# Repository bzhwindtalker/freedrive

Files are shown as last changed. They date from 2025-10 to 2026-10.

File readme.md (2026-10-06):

# Freedrive — Open Foil Assist

A lightweight, open-source electric **foil assist** system for riders who want help getting on foil without turning their setup into a full e-foil.

> Built in the open, tested in real water, and continuously improved with community feedback.

Freedrive full setup

---

## News

### 2026-10-06 — Season 4 turbine: first water test passed
- **Jet drive (turbine) first water test passed** (13 Sept): the S4 ducted-jet unit starts the small board and flies the big board with pumping. Max draw 41V/65A ≈ 2.66 kW. Motor-off touchdown drags, motor-on is clean.
- **5085 motor + titanium blades validated**: ~400 g lighter than the 6384 setup, smoothest feel of all tested motors.
- Test videos: [13 septembre 2026](https://www.youtube.com/watch?v=aBwcKk_be1A), [End of battery](https://www.youtube.com/watch?v=OXS7Xq_WdP4).
- Full log, photos and test data: [docs/turbine-development.md](docs/turbine-development.md)

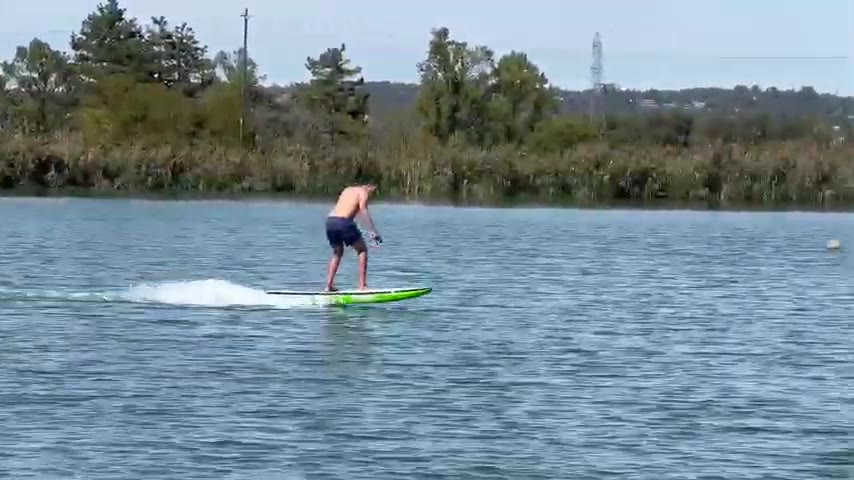
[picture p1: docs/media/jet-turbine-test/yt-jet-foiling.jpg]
S4 jet first test — foiling


### 2026-06 — 5085 motor testing + titanium blades
- 5085 motor ordered (same as @foilstate's proven design), ~400 g savings over the 6384 setup. Pod hacked, first water test 16 May.
- Titanium blades received 6 June and tested 15 June: zero post-processing, much sharper edges than alu.
- Community builds: **tkfoil** (Germany) replica reached 2.3 kW+ and 30+ starts/session. **Mikey** housing for Flysky 74100.
- Details below in "Latest verified updates".

### 2026-02 — Reliability updates
- EVA foam gaskets field-proven. Move to titanium screws after M8 stainless failures.
- No-CNC build path confirmed: print at home or via services (Craftcloud / Prototi).
- Corsica community build assembled with RS50 tabless cells (5.15 Ah).

Older entries: [NEWS.md](NEWS.md)

---

## Why Freedrive

- **Assist, not full propulsion**: designed for starts and recovery, not long-distance motoring.
- **Low-drag architecture**: slim under-board pod concept.
- **Open hardware workflow**: CAD, print files, wiring, and VESC configs are in this repo.
- **Field-proven iterations**: developed through long-term testing and community builds.

---

## Community Builds

Freedrive files have been shared with 15+ builders since Season 2. Active community replication builds in 2026 include:

| Builder | Location | Status | Notes |
| :--- | :--- | :--- | :--- |
| **tkfoil** | Germany | ✅ Running | Full replica, 2.3kW+, 30+ starts/session, FD LR6 prop |
| **Mikey** | — | 🔄 In progress | Housing adapted for Flysky 74100 VESC |
| Corsica builder | France | ✅ Running | RS50 tabless cells, custom blades |

See the [foil.zone development thread](https://foil.zone/t/light-assist-season-3/24787) for detailed build logs and ongoing discussions.

---

## Latest verified updates (June 2026)

From the build thread on foil.zone:

### 5085 Motor Testing — Weight Reduction Path
- **Post #208** — **5085 motor** ordered (same as @foilstate's proven design), targeting **~400g weight savings** over the 6384 reference setup.
- **Post #211–#220** — 5085 pod hacked and first water test completed with carbon prop + cotter pins. Despite unbalanced prop and improvised blade mounting, the motor performed well for flat-water starts. Confirmed sufficient for wave/DW assist with small board at 66kg/1600cm² foil.
- **Post #256** — **Titanium blades** received and ready for testing — expected to eliminate blade failure risk.

### Community Replication Builds
- **tkfoil** (Posts #188–#259) — Full replica build from scratch: Craft Cloud aluminum prints, custom spot-welded 12S1P battery with casting epoxy, external antenna setup. After VESC tuning (phase current 125A+, ERPM limit 35k), achieved **2.3kW+ output** and **30+ successful starts** with FD LR6 prop on DW board setup.
- **Mikey** (Posts #183–#187) — Housing adapted to Flysky 74100 VESC + Foil Drive motor components.

### Previous Highlights (Feb 2026)
- **Post #149** — Good results with **EVA foam seals** and move to **titanium screws** after M8 stainless fastener failures.
- **Post #150** — New build assembled in Corsica with **RS50 tabless cells (5.15Ah)**.
- **Post #152** — Clarification that the project needs **no CNC**: parts are printable at home or via services.

Links:
- https://foil.zone/t/light-assist-season-3/24787/208 (5085 motor)
- https://foil.zone/t/light-assist-season-3/24787/220 (5085 first test)
- https://foil.zone/t/light-assist-season-3/24787/256 (titanium blades)
- https://foil.zone/t/light-assist-season-3/24787/249 (community build success)
- https://foil.zone/t/light-assist-season-3/24787/149 (EVA seals)
- https://foil.zone/t/light-assist-season-3/24787/150 (Corsica build)
- https://foil.zone/t/light-assist-season-3/24787/152 (no CNC)

Corsica assembled unit (community build)

---

## System snapshot (V4 family)

| Feature | Specification |
| :--- | :--- |
| **System voltage** | 12S |
| **Battery current** | 50A |
| **Phase current** | 125A–150A |
| **Power** | ~2200W (6384 120KV reference setup) |
| **Weight** | ~2.8kg (controller, pod, battery) |
| **Expected starts** | 10 to 30 (depends heavily on rider/foil/board/conditions) |
| **Standard battery** | 12S1P 21700 |
| **Assist + one battery cost** | ~650€ |

---

## Who this is for (and not for)

### Good fit
- Experienced DIY riders comfortable with electrical + mechanical assembly.
- Downwind / pump / surf riders wanting launch assist.
- Builders ready to tune and iterate.

### Not a good fit
- Anyone expecting plug-and-play consumer product behavior.
- Riders wanting long powered cruising (use an e-foil platform).
- Builders unwilling to manage electrical/waterproofing/safety risk.

---

## Repository map

| Path | Purpose |
| :--- | :--- |
| `ORDER PRINTS/` | Parts intended for print-order workflow (including metal print parts). |
| `MAKE PARTS/` | Additional parts to manufacture/print. |
| `WIRE/` | Harness PDF + wiring references. |
| `PROGRAMM/` | VESC config files and controller programming notes. |
| `CAD/` | Main STEP and source CAD link. |
| `BOM of V4 system.xlsx` | Bill of materials. |
| `TODO.md` | Current task list / open improvements. |
| `NEWS.md` | Short timeline of recent project updates from the forum thread. |
| `docs/turbine-development.md` | Season 4 turbine (jet drive) development log, test data, and photos. |
| `docs/media/` | Media for the turbine log: jet test frames, build photos, 5085/ti photos. |

---

## Manufacturing guidance (current community direction)

Based on current thread guidance:

- **No CNC required** for the baseline project.
- **Base**: aluminum printed (service options cited: Craftcloud / Prototi), with home-print exploration possible.
- **Pod**: printable (PPA-CF FDM or PA12 SLS).
- **Battery box**: PETG print + cast-in-place deep-pour epoxy strategy.
- **Blades**: aluminum printed.
- **Hub**: PA12 SLS or PPA-CF.

Always validate thermal behavior, waterproofing quality, and mechanical integrity before riding.

---

## Scope and limitations

Freedrive is designed as a **lightweight launch/assist system**. It is not intended to replace paddling skill, surf positioning, or proper foil selection.

Known constraints:
- 12S1P travel limitations (airline Wh restrictions).
- Range is limited if motoring heavily.
- Performance depends strongly on total system setup and rider skill.
- This remains a DIY/open project with no warranty, no guaranteed support SLA, and evolving documentation.

---

## Safety (read this first)

A powered propeller under a board is inherently dangerous.

- Build and test at your own risk.
- Treat every test as if failure is possible.
- Verify sealing, fasteners, electrical insulation, and remote fail-safe behavior before water use.
- Keep clear procedures for arming/disarming and handling around people.

---

## Media & communication

- **Main development thread**: https://foil.zone/t/light-assist-season-3
- **Instagram**: https://www.instagram.com/adam_mercier_fr/
- **YouTube**: https://www.youtube.com/@bzhwindtalker29

---

## Credits

Project led by **Bzhwindtalker (Adam Mercier)** with major value from community testing and feedback on foil.zone.

If you build one, share your version and results in the thread — especially reliability, sealing, thermal data, and ride feedback.

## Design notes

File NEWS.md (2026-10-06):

# Freedrive News Log

A lightweight changelog-style digest from the main forum development thread:
https://foil.zone/t/light-assist-season-3

## 2026-10-05
- **#368** S4 board bottom glassed (wet lay, 2 × 125 gr glass + 200 gr carbon patch over dual stringer). Final board target ~4 kg.
- **#367** S4 board shaping progress photos.

## 2026-10-01
- **#364** S4 dedicated board build started: 163×52×80 mm EPS blank, no trench (parawing capability kept), dual stringer layout.

## 2026-09-17
- **#358** Dedicated S4 system concept v1: 95 mm 5080 jet, 12S2P removable 21700 battery (sealed, travel-fillable with 4S1P + wires), in-board cartridge intake in front of the mast. Board: dual plywood stringers or carbon tube, electronics on top.

## 2026-09-13
- **#355** **First water test of the S4 jet drive (turbine): success.** Small board starts (full battery only), big board flies with pumping. Max draw 41V/65A ≈ 2.66 kW. Motor-off touchdown = high drag, motor-on = clean. Air intake very sensitive.
- **#356** Test videos posted: [13 septembre 2026](https://www.youtube.com/watch?v=aBwcKk_be1A), [End of battery](https://www.youtube.com/watch?v=OXS7Xq_WdP4).

## 2026-09-08 to 2026-09-12
- **#354** Early jet feedback: very sensitive to air intake, balance OK, no scraping/vibration.
- **#353** @V_S: 5080 prop is low pitch (~95 mm) — good thrust, low speed.
- **#351** Jet rationale confirmed: safety (prop injury risk), DW + surf pop-up + displacement motoring.
- **#348** S4 jet concept detail: angled intake to save space and reduce cavitation. 5080 motor with supplied 4-blade prop.
- **#345** S4 jet concept first posted ("trying something new for season 4").

## 2026-08-17
- **#342** V4 prop pod lost in the water. Reliability rework started. 5085 motor re-ordered.

## 2026-06-15
- **#261** Ti prop test on 5085: perfect out of the box, very smooth when pumping. Previous DW score passed on 15 kt tailwind + slow Saône current.

## 2026-06-06
- **#256** Titanium blade set received (90 USD, alu + ti). Zero post-processing, edges sharper than alu. Hubs in PPA-GF 100% infill.

## 2026-05-16
- **#220** 5085 first water test (unbalanced carbon prop, cotter pins): felt stronger than maytech 6374, lower drag on pod touchdown, easy starts in small chop.
- **#216** Printed carbon prop failed (zero impregnation). Ordered two printed prop sets + one titanium set.

## 2026-05-12 to 2026-05-13
- **#211** 5085 pod hack in progress. SUP flat-start training log: 80% success on Condor M and Barracuda XL, goal 1000 cm² foil by end of year.
- **#208** 5085 motor ordered (same as @foilstate's design), ~400 g savings.

## 2026-02-27
- **#153** Community feedback: strong positive response to the project direction.
- **#152** Clarified build path: no CNC required; major parts can be printed at home or ordered from print services.

## 2026-02-26
- **#150** Community build assembled in Corsica with RS50 tabless cells (5.15Ah) and custom blade testing.
- **#149** Field-proven sealing + reliability updates: EVA foam gasket success and switch toward titanium screws after stainless M8 issues.

## 2026-02-23 to 2026-02-25
- **#142–#145** Active community experimentation on sealed battery compartment concepts and foaming TPU gasket materials.

## 2026-02-18
- **#140** Ride feedback on high motor position (blades ~20mm from board): better for pumping/weight centralization, harder upwind in chop.

## 2026-02-15
- **#135** Morocco trip debrief + setup evolution plans (new board, tabless battery direction, vibration issue noted on motor pod).

---

If you want to contribute, post your build data with:
- conditions
- foil/board setup
- battery details
- reliability notes (sealing, fasteners, thermal)
- what failed / what improved

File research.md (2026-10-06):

# Foil Assist Jet System — Research

Research on water jet / impeller propulsion for foil assist system.
Context: Freedrive S4 jet duct concept, comparison with Flite AMP,
and smaller-diameter (40-60mm) impeller options for reduced system thickness.

Full build/test log with photos and video references:
[docs/turbine-development.md](docs/turbine-development.md)

---

## 1. Current Setup (Freedrive S4 Jet)

- Motor: 5080, 4-blade prop, ~95mm pitch (too low per @V_S on foil.zone)
- Battery: 12s1p P45B = **199Wh** (NOT 700Wh — corrected)
- Max draw: 41V/65A = **2.66kW**
- ESC: BWESC 220A (80V rated, 16s possible)
- VESC config: [PROGRAMM/vesc_mcconf_freedrive.xml](PROGRAMM/vesc_mcconf_freedrive%20(1).xml)
- Weight: ~1.5-2kg (pod + motor + prop)
- Test results (13 Sept 2026):
  - Small board: starts only with full battery, 41V/65A = battery hammered
  - Big board: easy flying with pumping, transition to full flight not easy
  - Touchdown motor off = high drag, motor on = drag OK
  - Air intake sensitive (confirmed)
  - Pod lost in water (17 Aug 2026)

---

## 2. Flite AMP Comparison

| Spec | Freedrive S4 | Flite AMP (4'2" S) |
|---|---|---|
| Board | ~25L / 7'2 | 4'2" 27L carbon |
| Board weight (dry) | ~2.5kg | 2.94kg (6.5lbs) |
| Jet unit | 5080 + 4-blade prop + duct | Enclosed impeller, alu anodised |
| Jet weight | ~1.5kg | 2.3kg (incl 2 cells) |
| Battery | 12s1p P45B = **199Wh** | 2x AMPCell = **284Wh** |
| Battery weight | ~1.5kg | 2.0kg |
| Battery voltage | 41V (sag) | 50.4V nominal (58.8-42V) |
| Max power | 2.66kW | ~1.5-2kW (est) |
| Max thrust | ~25kg | 25kg (confirmed) |
| Total system weight | ~6.5-7kg | 7.2kg |
| Control | Maytech RX + BWESC 220A (continuous throttle) | LAUNCHPad + Flite App (10s fixed cycle) |
| Touchdown drag | HIGH (motor off) | LOW (enclosed, no prop to catch) |
| Air intake | Sensitive (open duct) | No (fully enclosed) |
| Price | ~500-800€ | 7,924€ (set) / 3,849€ (jet) |
| AMPCell weight | — | 1.0kg each |
| AMPCell charge time | — | 1 hour |
| AMPCell safety | — | Humidity sensor, PCM thermal, sight glass, fly-safe |

### Flite AMP key specs (from official + reviews)
- 25kg max thrust (2x AMPCells)
- 142Wh per AMPCell, 50.4V nominal
- 1.0kg per AMPCell
- Fully enclosed impeller, anodised aluminium, precision bushes
- 10s thrust cycle: moderate → high → moderate → off
- Board first, jet second design philosophy
- Jet swaps out in seconds
- Price: $3,849 USD (jet), $7,924 USD (4'2" set)

### Where Freedrive wins
- Price (10-15x cheaper)
- Continuous throttle control (vs 10s fixed cycle)
- Higher sustained power (2.66kW vs ~1.5-2kW)
- Customizable, repairable, open source
- Can use existing boards

### Where Flite wins
- Touchdown drag (enclosed = no drag when off)
- Integration (in-board vs on-mast)
- Safety systems (humidity sensor, thermal, fly-safe)
- Prop/impeller efficiency (optimized)
- No air intake sensitivity

### Links
- Official: https://fliteboard.com/pages/flitelab-amp
- Product: https://fliteboard.com/products/ampjet_board-set
- Jet: https://fliteboard.com/products/ampjet
- Review: https://foilsurfing.net/flitelab-amp-board-initial-thoughts/
- AMPCell: https://www.kitepower.com.au/products/flitelab-amp-cell

---

## 3. Smaller Impeller Analysis (40-60mm)

### Physics
Thrust ∝ D² × pitch × RPM² (approx)

At 2.66kW, to maintain ~25kg thrust:
- 80mm (current): 6,500rpm
- 60mm: need **8,667rpm**
- 50mm: need **10,400rpm**
- 40mm: need **13,000rpm**

All achievable with high-KV motor + 12s (41V).

### Thickness comparison
| System | Diameter | Length | Thickness |
|---|---|---|---|
| Freedrive 5080 | 80mm | ~150mm | 80mm |
| 60mm 2-stage | 60mm | ~130mm | 60mm |
| HPW40 (40mm) | 40mm | ~120mm | 40mm |
| Flite AMP | ~150mm | ~200mm | 150mm (in-board) |

60mm = 25% thinner than 5080, 60% thinner than Flite.

### Recommended motor for 60mm
- 5065 800-1000KV → 10,000-12,000rpm at 41V
- 5070 600-800KV → 8,000-10,000rpm at 41V
- Weight: 300-400g
- Power: 2-3kW

---

## 4. Open Source Jet Pump / Impeller Designs

### 4.1 HPW40 — 40mm 2-Stage Water Jet Drive (BEST MATCH)

- **URL**: https://youmagine.com/designs/1d90c387-66b6-4e87-a7b4-b5b339b6804f
- **Also**: https://cults3d.com/en/3d-model/game/hpw40-2-stage-water-jet-pump-wasserstrahlantrieb
- **Author**: HillPrinties
- **Diameter**: 40mm nominal
- **Stages**: 2 (like jet ski)
- **Designed for**: 4074 1400KV motor, 150A ESC, 3-6S LiPo
- **Power**: 2.0-2.5kW
- **Includes**: housing, stator, stator housing, 2 impellers, control nozzle, reverse flap, V8 motor cover
- **3D printable**: PA12/ABS-CF recommended
- **Price**: $20.50 STL (YouMagine) / $179 alu kit (vajjexrc)
- **Weight**: ~500-700g (printed)
- **Components needed** (not included):
  - 4074 1400KV brushless motor
  - 150A ESC
  - 2x 3S LiPo
  - 1-2 25kg waterproof servo
  - 1x shaft seal ring 5x16x5
  - 2x sealed stainless steel ball bearing 5x13x4

### 4.2 54mm Jet Drive

- **URL**: https://www.printables.com/model/179699-water-jet-pump-jet-drive-54mm-pump-jet
- **Author**: Andrew W.
- **Diameter**: 54mm
- **Use**: RC boat, used 2x for electric surfboard
- **Single-stage** design
- Free STL

### 4.3 80mm Water Jet (Mixed-Flow)

- **URL**: https://www.thingiverse.com/thing:5247333
- **Diameter**: 80mm
- **Design**: Mixed-flow (higher static pressure than axial)
- **Status**: Experimental prototype
- **Target**: Kayaks, surfboards

### 4.4 Commercial CNC Impellers (AliExpress)

- 40mm/60mm/70mm/85mm/100mm/120mm range
- 7075 aluminum, 2-3 blades
- 4-5mm shaft
- Price: $20-50
- Some kits include 3674 motor + water cooling jacket
- Not open source, but cheap and proven
- Search: "water jet impeller" on AliExpress

### 4.5 SSS 4074 Motor (for HPW40)

- **40mm diameter x 74mm long**
- KV options: 1400 / 1850 / 2200 / 2500
- 4-pole inner runner
- Water cooling jacket included
- Efficiency >90%
- Weight: ~750g (with jacket)
- **URLs**:
  - https://www.tflhobby.com/products/sss-4074-series-4-poles-inner-runner-brushless-motor-water-cooling-for-rc-boat-electric-surfboard
  - https://www.noahsrcark.co.uk/products/dcf8ed7467/131444000002103471
  - https://www.aliexpress.com/item/32848316583.html

---

## 5. Parametric Turbine / Impeller CAD Tools

### 5.1 TurboDesigner (CLOSEST TO WHAT YOU WANT)

- **URL**: https://github.com/OpenOrion/turbodesigner
- **Install**: `pip install turbodesigner`
- **What**: Parametric turbomachinery design tool
- **Input**: pressure ratio, mass flow, RPM
- **Output**: Mean-line thermodynamic analysis, blade flow analysis, 3D STEP files
- **Currently**: Axial compressor focused, plans for axial turbines + turbopumps
- **Methods**: Free-vortex theory, Johnsen-Bullock deviation, DCA + NACA 65 airfoils
- **CAD**: CadQuery (OpenCASCADE), exports STEP
- **Note**: Designed for air (compressors), needs adaptation for water (lower speed, higher density)

### 5.2 ParaturboCAD

- **URL**: https://github.com/SoheylM/paraturbo-cad
- **What**: Python + CadQuery, parametric centrifugal impeller design
- **Context**: ASME 2024 research paper (gas-bearing turbocompressors)
- **Classes**: IMPELLER(), SGTB(), ROTOR(), HELPER()
- **Use**: Overkill for water jet, but blade geometry code reusable
- **Install**: Python 3.11, Conda, `pip install -r requirements.txt`

### 5.3 RadialTurboMacrosFreeCAD

- **URL**: https://github.com/20jeka08
- **What**: FreeCAD Python macros for parametric radial impeller generation
- **Use**: FreeCAD (free), export STEP/STL
- **Note**: Radial, not axial, but blade geometry adaptable

### 5.4 CFturbo (NOT OPEN SOURCE)

- **URL**: https://cfturbo.com
- **What**: Professional turbomachinery design + CFD
- **Use**: Axial impeller design tutorial available (PDF)
- **Cost**: Commercial, expensive
- **Link**: https://cfturbo.com/fileadmin/content/down/tutorials/CFturbo_Axial_Impeller.pdf

---

## 6. Recommendations

### Option A: Print (fastest, 1-2 weeks)
1. Download HPW40 STL from YouMagine ($20)
2. Scale to 60mm in Fusion360 (50% scale)
3. Print housing in PA12 (CraftCloud, ~€30-50)
4. Get 5065 800-1000KV motor (AliExpress, ~$80-120)
5. Test with existing BWESC + 12s1p
6. If thrust insufficient: go 12s2p (398Wh)

### Option B: CNC (best performance, 2-4 weeks)
1. Use TurboDesigner to generate 60mm axial impeller
2. Export STEP, send to CNC shop or China
3. 7075 aluminum, 3-5 blades
4. Cost: $50-150
5. Test with 5065/5070 high-KV motor

### Option C: Buy (fastest, 1-2 weeks shipping)
1. AliExpress 60mm CNC impeller ($30)
2. 5065 high-KV motor ($100)
3. Test immediately with existing ESC + battery

### Battery upgrade path
- Current: 12s1p P45B = 199Wh (hammered at 2.66kW)
- Option 1: 12s2p = 398Wh, ~3kg, 65A → 32A per pack
- Option 2: 16s1p = 266Wh, higher voltage, less current (BWESC handles 80V)
- Option 3: 12s1p P50B = 266Wh, still 1x C at 65A

### Key gaps to solve
1. **Prop pitch**: 95mm too low → need higher pitch for DW speed
2. **Air intake**: Sensitive → redesign intake or add shroud
3. **Touchdown drag**: Motor off = high drag → folding prop or gate
4. **Thermal**: No cooling for 5080 at 65A sustained → monitor temp
5. **Pod retention**: Lost pod in water → need retention mechanism
6. **Battery**: 199Wh too small for 2.66kW → 12s2p or 16s

---

## 7. Links

### Freedrive repo
- https://github.com/bzhwindtalker/freedrive
- CAD (Onshape): https://cad.onshape.com/documents/69e061cb4c8645619cdbc4fc/w/9ab742b640d16d4199051770/e/b0ebddbcfe0ccffe19f3a73c
- BOM: [BOM of V4 system.xlsx](BOM%20of%20V4%20system.xlsx)
- VESC config: [PROGRAMM/vesc_mcconf_freedrive.xml](PROGRAMM/vesc_mcconf_freedrive%20(1).xml)
- Wiring: [WIRE/HARNESS%20FREEDRIVE%20V4.pdf](WIRE/HARNESS%20FREEDRIVE%20V4.pdf)

### Forum
- Main thread: https://foil.zone/t/light-assist-season-3/24787
- S4 jet test (13 Sept): https://foil.zone/t/light-assist-season-3/24787/355
- 5080 motor: https://foil.zone/t/light-assist-season-3/24787/348
- V_S prop pitch comment: https://foil.zone/t/light-assist-season-3/24787/353

### Flite AMP
- Official: https://fliteboard.com/pages/flitelab-amp
- Product: https://fliteboard.com/products/ampjet_board-set
- Jet: https://fliteboard.com/products/ampjet
- AMPCell: https://www.kitepower.com.au/products/flitelab-amp-cell
- Review: https://foilsurfing.net/flitelab-amp-board-initial-thoughts/

### Jet pump designs
- HPW40: https://youmagine.com/designs/1d90c387-66b6-4e87-a7b4-b5b339b6804f
- 54mm: https://www.printables.com/model/179699-water-jet-pump-jet-drive-54mm-pump-jet
- 80mm: https://www.thingiverse.com/thing:5247333
- STLFinder (118 models): https://www.stlfinder.com/3dmodels/water-jet-impeller/

### Turbine CAD tools
- TurboDesigner: https://github.com/OpenOrion/turbodesigner
- ParaturboCAD: https://github.com/SoheylM/paraturbo-cad
- RadialTurboFreeCAD: https://github.com/20jeka08
- CFturbo tutorial: https://cfturbo.com/fileadmin/content/down/tutorials/CFturbo_Axial_Impeller.pdf

### Motors
- SSS 4074: https://www.tflhobby.com/products/sss-4074-series-4-poles-inner-runner-brushless-motor-water-cooling-for-rc-boat-electric-surfboard
- SSS 4074 (Ali): https://www.aliexpress.com/item/32848316583.html

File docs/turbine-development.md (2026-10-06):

# Freedrive Season 4 — Turbine (Jet Drive) Development

Development log for the ducted jet drive (turbine) propulsion variant of Freedrive.
Context: replace the open propeller with a ducted jet for safety, touchdown drag,
and prop-loss immunity, while keeping the light-assist power class (~2-2.7 kW).

Main thread: https://foil.zone/t/light-assist-season-3/24787
Related analysis: [research.md](../research.md)

---

## 1. Why a turbine

- **Safety**: open prop close calls accumulate with hours. A ducted jet keeps the
  impeller behind a duct lip. This is the main driver (post #351).
- **Touchdown behavior**: open pod causes high drag on touchdown. A ducted unit
  idles much cleaner when the motor spins (post #355).
- **No prop loss**: no folding mechanism, no loose blades to shed.
- **Use case**: downwind starts, surf pop-up, displacement motoring between peaks.
  Same "Flite AMP class" target, open-source and repairable.

Trade-offs accepted for v1:
- Higher static pressure loss in duct → lower efficiency than open prop at flat out.
- Air intake sensitivity (open duct top).
- Touchdown with motor OFF is still a hard brake (funnel effect).

---

## 2. Timeline

| Date | Event | Thread ref |
| :--- | :--- | :--- |
| 2025-09 | Jet concept raised for S3 ("jet pod or EDF style" for safety) | [#131963](https://foil.zone/t/24787/131963) |
| 2026-05 | 5085 motor test path started (weight reduction, see [§4](#4-the-5085-motor-path)) | [#208](https://foil.zone/t/24787/208) |
| 2026-08-17 | V4 prop pod lost in the water. Reliability rework begins. 5085 re-ordered | [#342](https://foil.zone/t/24787/342) |
| 2026-09-05 | S4 jet concept posted ("trying something new for season 4") | [#345](https://foil.zone/t/24787/345) |
| 2026-09-08 | Concept detail: angled intake to save space + reduce cavitation. 5080 motor + 4-blade prop selected | [#348](https://foil.zone/t/24787/348) |
| 2026-09-12 | Bench/early water feedback: sensitive to air intake, balance OK, no scrape/vibration | [#354](https://foil.zone/t/24787/354) |
| 2026-09-13 | **First water test success** (see [§5](#5-first-water-test--13-sept-2026)). Test videos posted | [#355](https://foil.zone/t/24787/355), [#356](https://foil.zone/t/24787/356) |

---

## 3. Test unit (S4 jet v1)

| Item | Spec |
| :--- | :--- |
| Motor | 5080, 4-blade prop supplied, ~95 mm pitch (low pitch per [@V_S](https://foil.zone/t/24787/353)) |
| Intake | Angled duct entry (space saving + cavitation reduction) |
| Battery | 12S1P 21700 P45B, 199 Wh |
| ESC | BWESC 80 V 220 A |
| Max draw seen | 41 V / 65 A ≈ **2.66 kW** |
| Mount | High on the mast, higher than the usual V4 pod |
| Weight | ~1.5–2 kg (pod + motor + prop) |

Concept and build photos (from the thread):

| Concept sketch | Intake detail | Angled 5080 + 4-blade prop | Wiring |
| :--- | :--- | :--- | :--- |
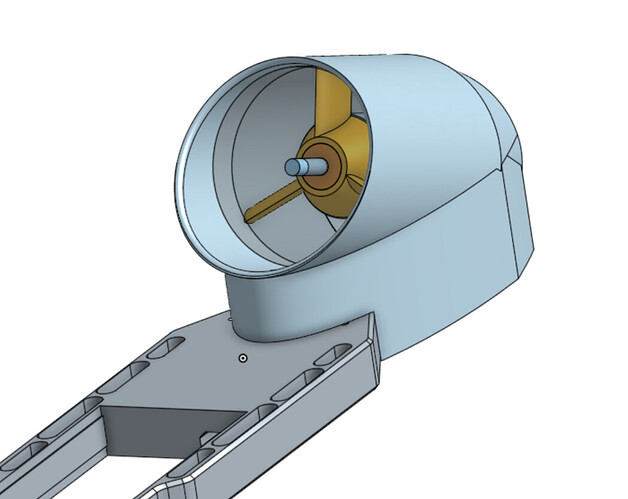
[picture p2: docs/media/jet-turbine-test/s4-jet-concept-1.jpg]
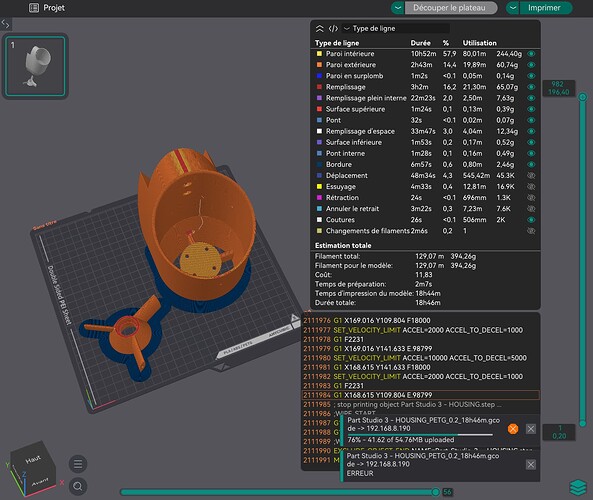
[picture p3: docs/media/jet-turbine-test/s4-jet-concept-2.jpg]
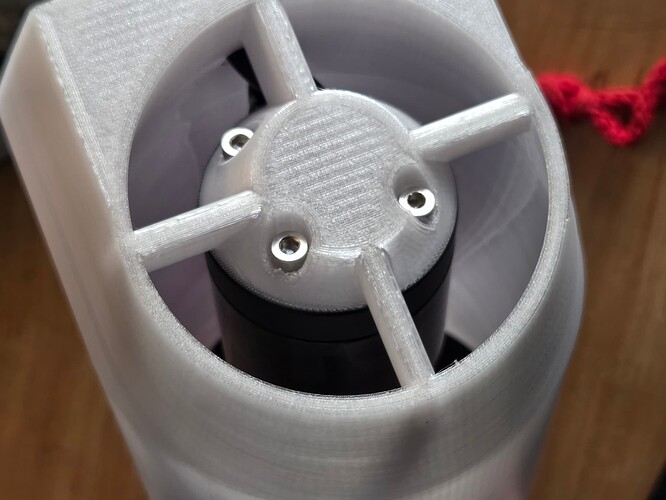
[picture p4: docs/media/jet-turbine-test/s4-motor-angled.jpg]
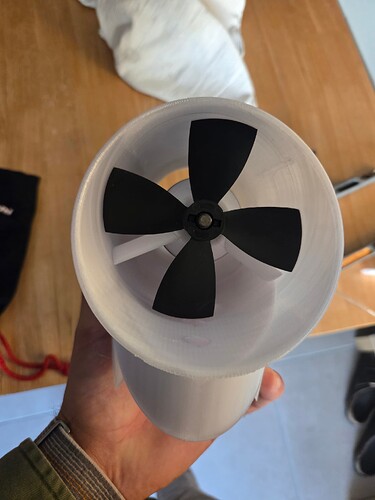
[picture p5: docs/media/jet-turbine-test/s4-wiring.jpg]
|  |  |  |  |

---

## 4. The 5085 motor path (context)

The turbine work follows directly from the 5085 motor swap, which cut ~400 g from
the V4 prop setup and gave the cleanest feel of all tested motors.

- **2026-05-12** — 5085 ordered (same motor as @foilstate's proven design).
- **2026-05-13** — V4 pod hacked to fit the 5085. Hub printed (PETG-GF cracked
  after one session → PPA/PA 100% infill hubs).
- **2026-05-16** — First 5085 test with unbalanced carbon prop + cotter pins:
  felt stronger than the maytech 6374, lower drag on pod touchdown, easy
  starts in small chop. (post [#220](https://foil.zone/t/24787/220))
- **2026-06-06** — Titanium blade set received (90 USD, alu + ti set). No post
  processing needed, edges sharper than alu. (post [#256](https://foil.zone/t/24787/256))
- **2026-06-15** — Ti prop test: perfect out of the box. 5085 + ti setup "very
  smooth, gets forgotten when pumping". Previous DW score passed on 15 kt
  tailwind + slow Saône current. Ti bolts + ti blades credited. (post [#261](https://foil.zone/t/24787/261))

5085 / Ti build photos:

| Hacked 5085 pod | First 5085 water test | Ti blade set |
| :--- | :--- | :--- |
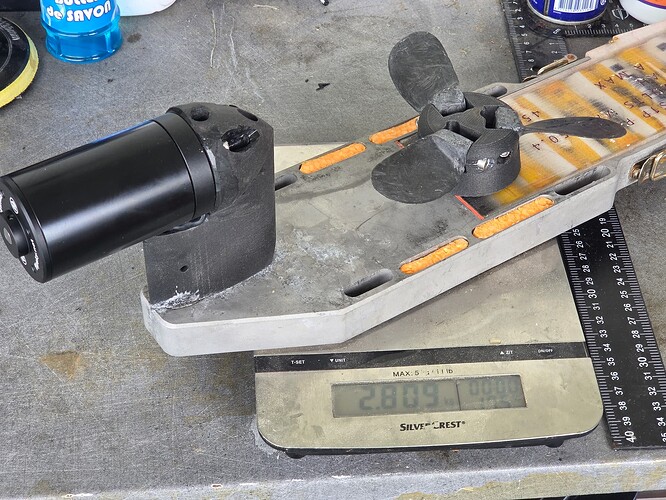
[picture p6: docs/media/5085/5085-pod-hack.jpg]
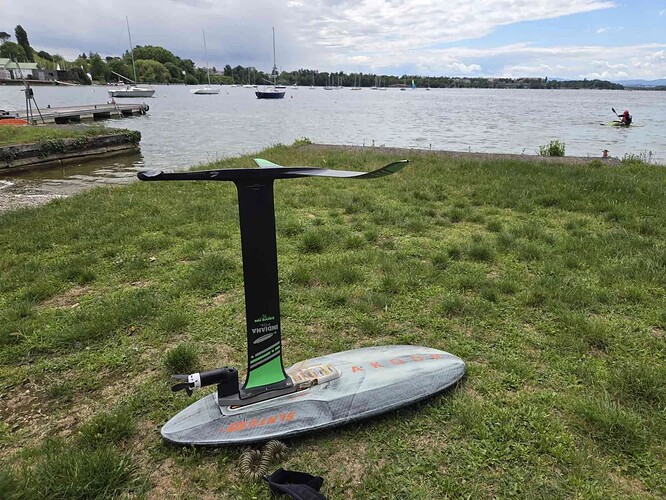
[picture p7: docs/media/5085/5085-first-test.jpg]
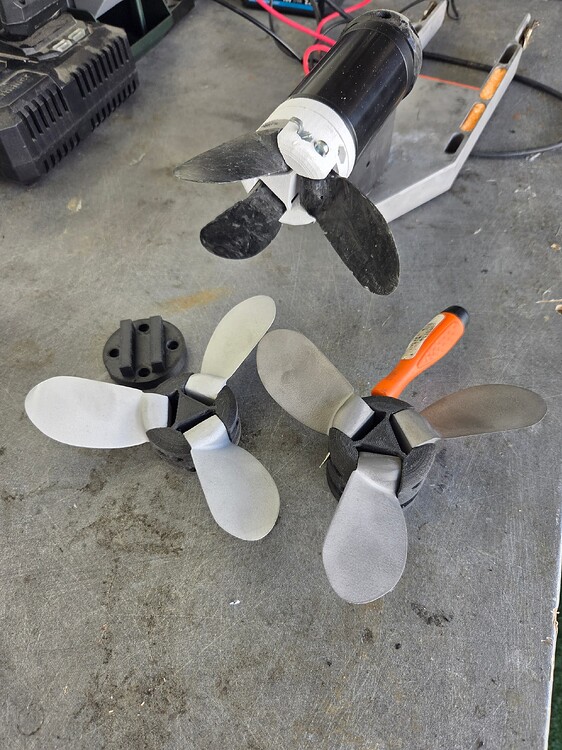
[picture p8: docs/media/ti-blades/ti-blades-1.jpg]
|  |  |  |

---

## 5. First water test — 13 Sept 2026

Results from the first dedicated jet test (post [#355](https://foil.zone/t/24787/355)):

- **System works.** Small board started a few times, but only with full battery.
- **Battery hammered**: 41 V / 65 A at full charge on 12S1P. 199 Wh is too small
  for this duty cycle. 12S2P is the fix.
- **Big board**: easy flying with some pumping. Transition to fully flying not easy.
- **Touchdown**: motor off = lot of drag (funnel brake). Motor spinning = drag much less noticeable.
- **Air intake**: confirmed very sensitive (post #354).
- **Balance**: no scraping or vibration felt.

Test screenshots (from the posted videos, [13 septembre 2026](https://www.youtube.com/watch?v=aBwcKk_be1A) and [End of battery](https://www.youtube.com/watch?v=OXS7Xq_WdP4)):

| Start on small board | Foiling with the jet | Flight, big board |
| :--- | :--- | :--- |
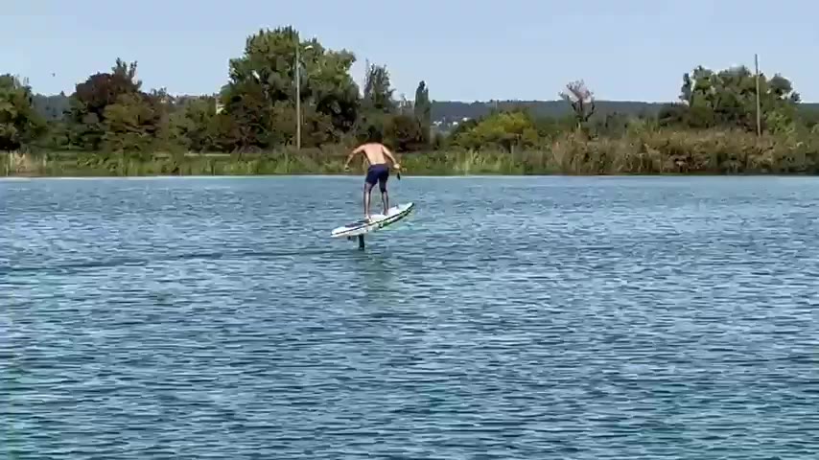
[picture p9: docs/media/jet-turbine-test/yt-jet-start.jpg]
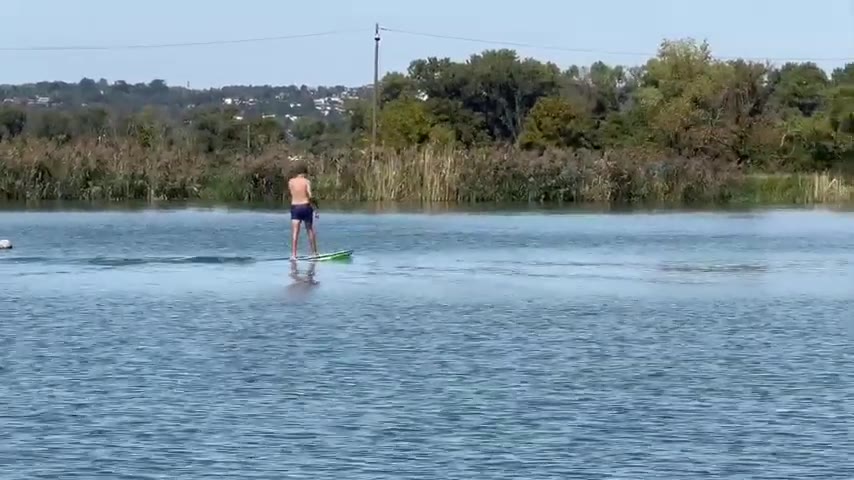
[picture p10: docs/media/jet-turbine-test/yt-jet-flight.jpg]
|  |  |  |

On-site photos from the test day (post #355):

| Jet test 1 | Jet test 2 |
| :--- | :--- |
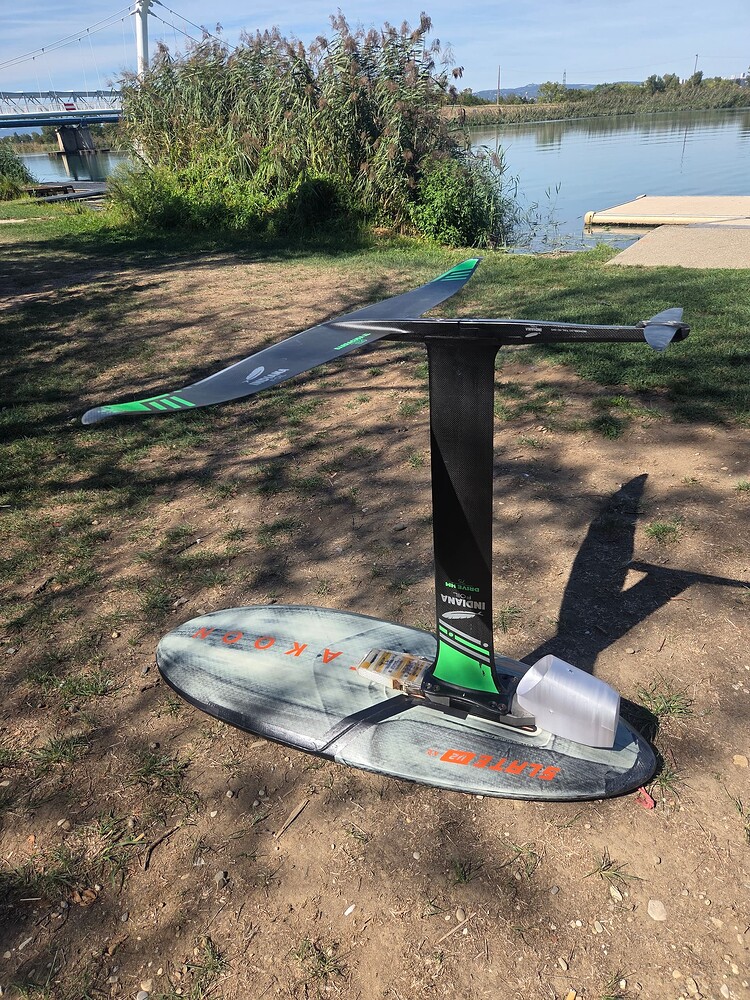
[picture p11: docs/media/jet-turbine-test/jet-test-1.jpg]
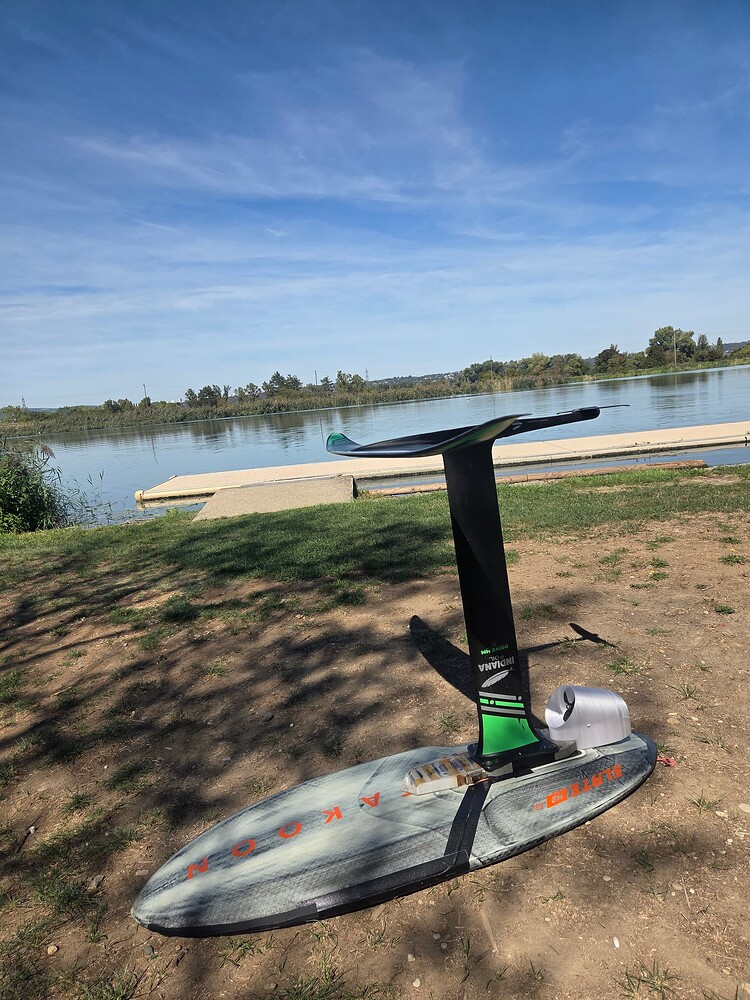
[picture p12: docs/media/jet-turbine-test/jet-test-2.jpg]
|  |  |

---

## 6. Known gaps (carried from research.md, updated by the tests)

1. **Prop pitch**: 95 mm too low for DW speed. Higher pitch impeller next.
2. **Air intake**: sensitive → shroud or redesigned intake.
3. **Touchdown drag**: motor-off funnel brake → gate or folding element study.
4. **Thermal**: 5080 at 65 A sustained, no active cooling → monitor.
5. **Pod retention**: pod lost in water (17 Aug 2026) → retention mechanism.
6. **Battery**: 199 Wh too small for 2.66 kW → 12S2P (398 Wh) or 16S1P.

---

## 7. Links

- S4 jet concept: https://foil.zone/t/light-assist-season-3/24787/345
- Angled intake + motor: https://foil.zone/t/light-assist-season-3/24787/348
- Air intake sensitivity: https://foil.zone/t/light-assist-season-3/24787/354
- First water test: https://foil.zone/t/light-assist-season-3/24787/355
- Test videos: https://foil.zone/t/light-assist-season-3/24787/356
  - [13 septembre 2026](https://www.youtube.com/watch?v=aBwcKk_be1A)
  - [End of battery](https://www.youtube.com/watch?v=OXS7Xq_WdP4)
- 5085 motor: https://foil.zone/t/light-assist-season-3/24787/208
- Ti blades: https://foil.zone/t/light-assist-season-3/24787/256
- Ti prop test: https://foil.zone/t/light-assist-season-3/24787/261
- Jet research (impellers, Flite AMP, CAD tools): [research.md](../research.md)

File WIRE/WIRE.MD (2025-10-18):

## Wiring Schematics

| Connection | From | To | Notes |
|---|---|---|---|
| **Power (5V, GND)** | Controller | MKS Express + Receiver | Common 5V and GND for both |
| **CAN Bus** | Controller (CL, CH) | MKS Express (CAN-L, CAN-H) | For VESC logging and Bluetooth via the VESC Express |
| **UART** | Controller (TX, RX) | Receiver (RX, TX, GND) | For telemetry / remote uplink |
| **PPM** | Receiver (PPM output) | Controller (PPM input or signal out to VESC) | For throttle / RC control |

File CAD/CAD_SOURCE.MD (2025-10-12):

CAD SOURCE @onshape

non commercial licence cc by nc 4.0
Design by ADAM MERCIER 2024-2025

Happy to collaborate on the design, and keep me updated if you build one :wink:

Link :

https://cad.onshape.com/documents/69e061cb4c8645619cdbc4fc/w/9ab742b640d16d4199051770/e/b0ebddbcfe0ccffe19f3a73c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

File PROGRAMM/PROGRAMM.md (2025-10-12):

VESC SEETINGS FILES GOES HERE

VESC EXPRESS, VESC TOOL RESSOURCES ALSO HERE

CONFIG FOR ALTERNATE ESC CAN ALSO GO HERE

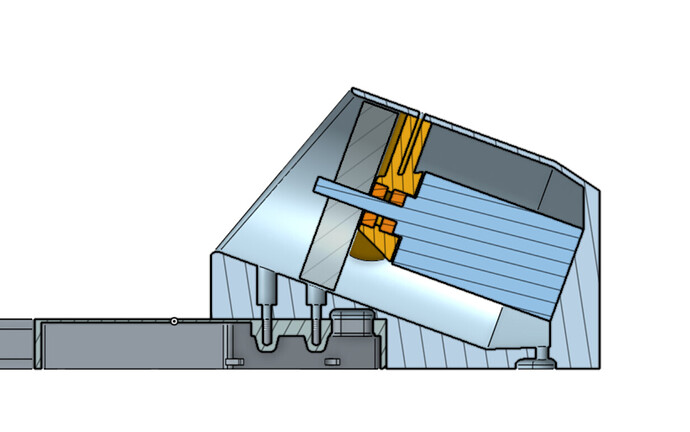
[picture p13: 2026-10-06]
docs/media/jet-turbine-test/s4-jet-concept-4.jpg

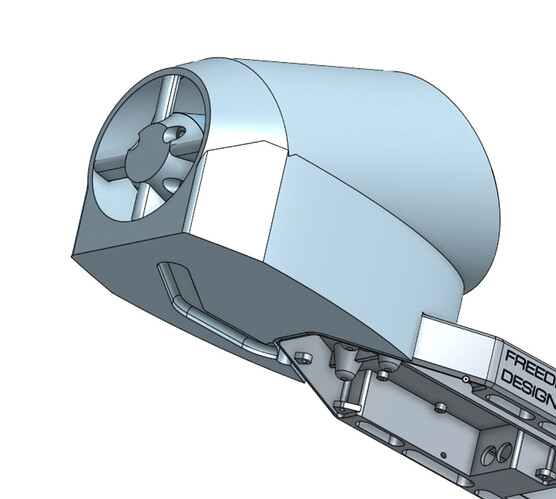
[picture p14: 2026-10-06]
docs/media/jet-turbine-test/s4-jet-concept-3.jpg

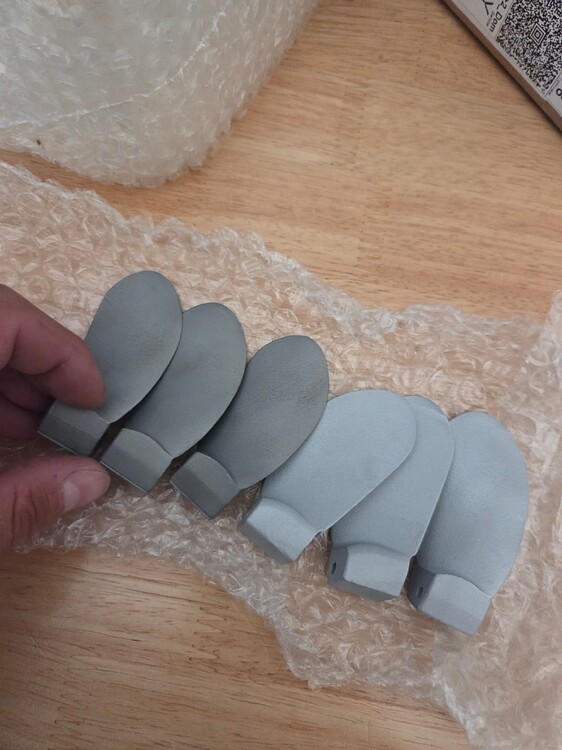
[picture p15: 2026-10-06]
docs/media/ti-blades/ti-blades-3.jpg

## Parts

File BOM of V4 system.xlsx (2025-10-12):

ASSIST BOM (A)
BL1 | BL2 | BL3 | Quantity | Name | Description | Part number | Brand | Revision | Material | COST est | Vendor1 | Vendor2 | Mass (gr) | Bom weight | Bom cost
A1 |  |  | 1 | CTRL V4 | Controller housing, printed in aluminium, from craftcloud or JLCPCB |  |  |  | PRINTED ALU | 175.00 € | CRAFTCLOUD | JLCPCB | 402 | 402 | 175.00 €
A2 |  |  | 1 | CTRL COVER | Cover for electronics |  | HOME PRINT |  | Transparent PETG | 1.00 € | OVERTURE | CRAFTCLOUD |  | 0 | 1.00 €
A3 |  |  | 1 | XTPB-M | XT90 waterproof connector (has no hole between pins and housing, will not leak potting compound) | XT90HW-M | AMASS |  | - None - | 2.00 € | ALI |  |  | 0 | 2.00 €
A4 |  |  | 1 | MR60-M | MALE MR60 connector |  | AMASS |  | - None - | 2.00 € | ALI |  |  | 0 | 2.00 €
A5 |  |  | 1 | maytech RX | Maytech receiver | MTSKR1905WF V3 | MAYTECH |  | - None - | 30.00 € | ALI |  |  | 0 | 30.00 €
A6 |  |  | 1 | POD V3 | Pod assembly |  |  |  | - None - |  | - None - |  |  | 0 | 0.00 €
 | A6.1 |  | 1 | TRIPALE ALU | Propeller assembly |  |  |  | - None - |  | - None - |  |  | 0 | 0.00 €
 |  | A6.1.1 | 3 | DIN 934 - M4 x 0.7 stainless steel | NUT |  |  |  | STAINLESS STEEL | 1.00 € | ALI |  |  | 0 | 3.00 €
 |  | A6.1.2 | 4 | DIN 912 - M4 x 0.7 x 10 Stainless steel | Hexagon Socket Head Cap Screw |  |  |  | STAINLESS STEEL | 1.00 € | ALI |  |  | 0 | 4.00 €
 |  | A6.1.3 | 3 | DIN 912 - M4 x 0.7 x 35 Stainless steel | Hexagon Socket Head Cap Screw |  |  |  | STAINLESS STEEL | 1.00 € | ALI |  |  | 0 | 3.00 €
 |  | A6.1.4 | 1 | HUB 6384 |  |  |  |  | PA12 MJF | 12.00 € | CRAFTCLOUD |  |  | 0 | 12.00 €
 |  | A6.1.5 | 1 | 6384 120KV |  |  | BDUAV |  | - None - | 55.00 € | CRAFTCLOUD |  |  | 0 | 55.00 €
 |  | A6.1.6 | 3 | BLADE | ALU PRINTED |  |  |  | PRINTED ALU | 20.00 € | CRAFTCLOUD |  |  | 0 | 60.00 €
 | A6.2 |  | 1 | POD Simplified |  |  |  |  | PA12 MJF | 20.00 € | CRAFTCLOUD |  |  | 0 | 20.00 €
A7 |  |  | 1 | 12S1P BATT | Battery assembly |  |  |  | N/A |  | - None - |  |  | 0 | 0.00 €
 | A7.1 |  | 1 | XT90S-F | Anti-spark XT90 |  | AMASS |  | - None - | 2.00 € | ALI |  |  | 0 | 2.00 €
 | A7.2 |  | 1 | 12S1P BOX |  |  | HOME PRINT |  | Transparent PETG | 2.00 € | OVERTURE |  |  | 0 | 2.00 €
 | A7.3 |  | 12 | 21700 cell |  |  |  |  | - None - | 5.00 € | NKON | AKKUTELLE | 72 | 864 | 60.00 €
 | A7.4 |  | 1 | NICKEL STRIP | Nickel/copper strip for battery build |  |  |  | Nickel /copper | 3.00 € | https://fr.aliexpress.com/item/1005008522119895.html |  |  | 0 | 3.00 €
 | A7.5 |  | 1 | RTL POGO 14 | 14 pin RTL POGO connector, pre-wired, flat part on battery side | 2x7 pin |  |  | - None - | 4.50 € | https://fr.aliexpress.com/item/1005006488295870.html |  |  | 0 | 4.50 €
 | A7.6 |  | 1 | EPOXY (POTTING, DEEP POUR) | USE SLOW SET EPOXY, for deep pour / potting. REGULAR EPOXY COULD GO THERMAL AND EXPLODE |  | DIPOXY |  | EPOXY | 5.00 € | AMAZON |  | 150 | 150 | 5.00 €
A8 |  |  | 1 | bwesc 150 | HARRYM 220A VESC |  | HARRYM |  | - None - | 167.00 € | EASYFOIL |  |  | 0 | 167.00 €
 | A8.1 |  | 1 | VESC EXPRESS | Use this to get bluetooth on the vesc via CAN to retain the uart uplink on the maytech |  | MAKERBASE |  | - None - | 10.00 € | ALI |  |  | 0 | 10.00 €
A9 |  |  | 1 | MR60-F | FEMALE MR60 connector |  | AMASS |  | - None - | 2.00 € | ALI |  |  | 0 | 2.00 €
A10 |  |  | 1 | BATT SEAL | Cut from 1mm EVA foam or printed in TPU |  |  |  | EVA FOAM | 1.00 € | AMAZON | ALI |  | 0 | 1.00 €
A11 |  |  | 2 | _SK3-002A | Latch |  |  |  | Stainless Steel 316 | 6.00 € | AMAZON | ALI |  | 0 | 12.00 €
A12 |  |  | 4 | PZ Pan head screw M3x0.50 x 5 | PZ Pan head screw M3x0.50 x 5 Stainless Steel |  |  |  | Stainless Steel 316 | 0.25 € | ALI |  | 0.45 | 1.8 | 1.00 €
A13 |  |  | 3 | Hex socket head cap screw M5x0.80 x 75 | Hex socket head cap screw M5x0.80 x 75 Stainless Steel 316 |  |  |  | Stainless Steel 316 | 2.00 € | ALI |  | 13.6 | 40.8 | 6.00 €
A14 |  |  | 4 | Hex socket head cap screw M4x0.70 x 12 | Hex socket head cap screw M4x0.70 x 12 Stainless Steel 316 |  |  |  | Stainless Steel 316 | 0.75 € | ALI |  | 2.26 | 9.04 | 3.00 €
A15 |  |  | 1 | POD SEAL | Cut from 1mm EVA foam or printed in TPU |  |  |  | EVA FOAM | 1.00 € | AMAZON | ALI |  | 0 | 1.00 €
A16 |  |  | 1 | TPU PAD | Printed to avoid scratch on board and even out pressure |  | HOME PRINT |  | TPU | 2.00 € | ninjaflex | FLEXIFIL |  | 0 | 2.00 €
A17 |  |  | 5 | PH Countersunk flat head screw M3x0.5 x 6 | PH Countersunk flat head screw M3x0.5 x 6 Stainless Steel |  |  |  | Stainless Steel | 0.25 € | ALI |  | 0.45 | 2.25 | 1.25 €
A18 |  |  | 4 | Hex socket countersunk head screw M8x1.25 x 55 | To screw your foil on the board, check length before fully tightening! |  |  |  | Stainless Steel | 2.00 € | ALI |  | 24 | 96 | 8.00 €
A19 |  |  | 1 | Potting compound | Use 2 part potting compound, such as magic gel ray tech, or RTV1523 |  | BLUESTAR SILICONS |  | RTV SILICON | 5.00 € |  |  | 190 | 190 | 5.00 €
A20 |  |  | 1 | POWER WIRES | 10-12 AWG with 200°C insulation |  |  |  | - None -
A21 |  |  | 1 | THERMAL TAPE | Thermal transfer tape for insulating electrically but not thermally the bottom of the vesc. 35mm wide to match the PCB | 35mm wide 0.2mm thick |  |  | - None - |  | https://fr.aliexpress.com/item/1005003999350463.html
TOTALS >> |  |  |  |  |  |  |  |  |  |  |  |  |  | 1755.89 | 662.75 €
ACCESSORIES BOM (B)
B1 |  |  | 1 | BATTERY COVER | For transport and safety when storing the battery in wet environnement |  |  |  | FDM PRINTED | 1.00 € |  |  |  |  | 1.00 €
B2 |  |  | 1 | PROP GUARD | To avoid cuts or damage when handling the assist and for storage |  |  |  | FDM PRINTED | 2.00 € |  |  |  |  | 2.00 €
B3 |  |  | 1 | MAYTECH TX | Use this to control the motor | MTSKR1905WF V3 | MAYTECH |  | - None - | 80.00 € | ALI |  |  |  | 80.00 €
B4 |  |  | 1 | CHARGER | Use this to recharge the batteries |  |  |  | - None - | 25.00 € |  |  |  |  | 25.00 €
B5 |  |  | 1 | BALANCE ADAPTER | Male side of RTL POGO 14 pin, to your choice of 2x 6s or 12S balance plug |  |  |  | - None - | 4.50 € |  |  |  |  | 4.50 €
B6 |  |  | 1 | TOOLS YOU NEED | Things needed to assemble the system |  |  |  | - None -
 | B6.1 |  | 1 | Soldering iron | Need to solder some wire, 60-100w will be required |  |  |  | - None -
 | B6.2 |  | 1 | SPOT WELDER | Need something correct |  |  |  | - None -
 | B6.3 |  | 1 | Computer or phone with vesc tool | Vesc tool is free on PC and Android (APK sideload) |  |  |  | - None -
 | B6.4 |  | 1 | 3D PRINTER | You could also order all parts printed from craftcloud/others |  |  |  | - None -
B7 |  |  | 1 | Antenna extension | Coax cable with exposed ends used as a signal booster for full carbon boards. Run the antenna above the anttena of the assist with as little water as possible in between both antennas, the other side sould go on the deck of the board close to your throttle hand. Leave the anttena extension taped to the board and be done with signal issues. | 1.13mm coax cable |  |  | - None - | 0.62 € | https://fr.aliexpress.com/item/1005002336927377.html
TOTALS >> |  |  |  |  |  |  |  |  |  |  |  |  |  | 0 | 112.50 €

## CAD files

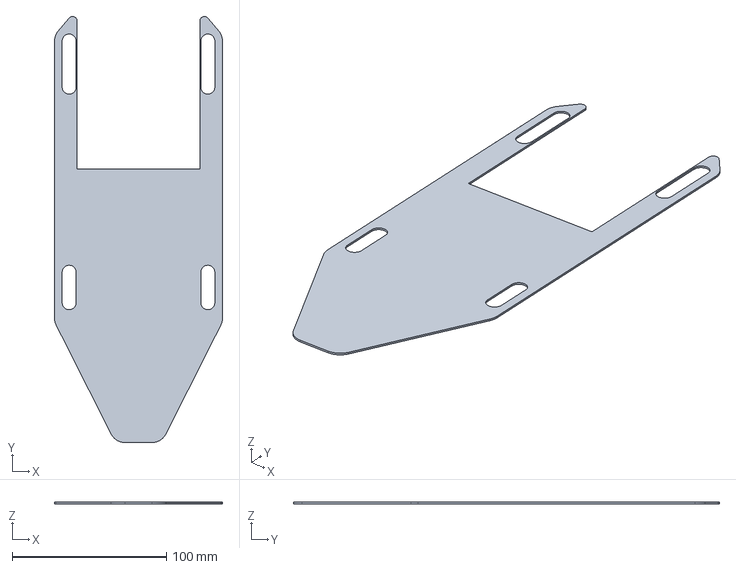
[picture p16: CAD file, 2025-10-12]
MAKE PARTS/A16_TPU_PAD.step
109.0 x 276.4 x 1.00 mm

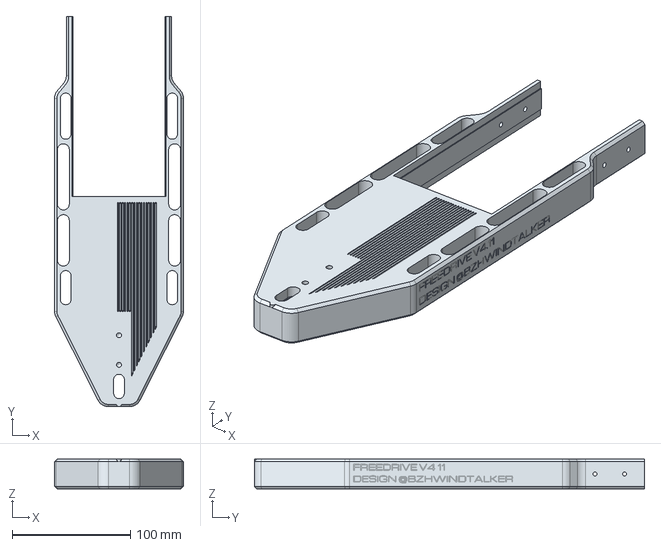
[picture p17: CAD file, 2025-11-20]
ORDER PRINTS/A1_CTRL_V4.step
109.0 x 329.9 x 25.0 mm

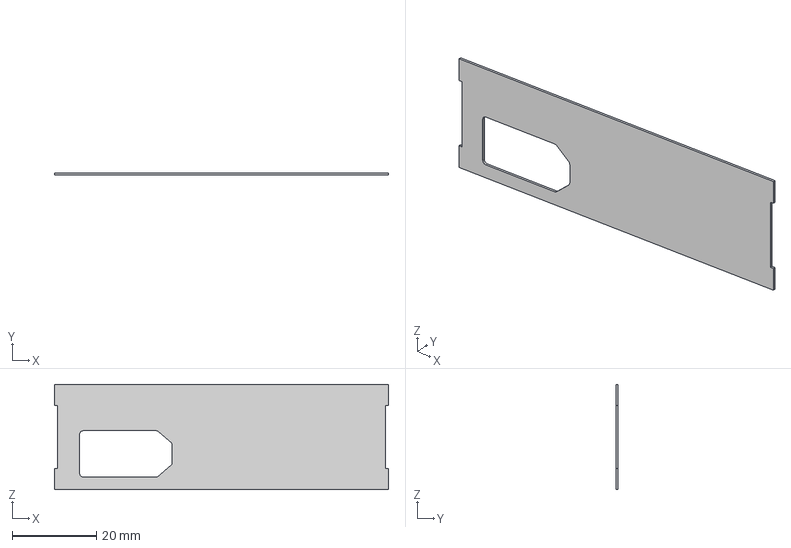
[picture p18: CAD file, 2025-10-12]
MAKE PARTS/A10_BATT_SEAL.step
79.5 x 0.5 x 25.0 mm

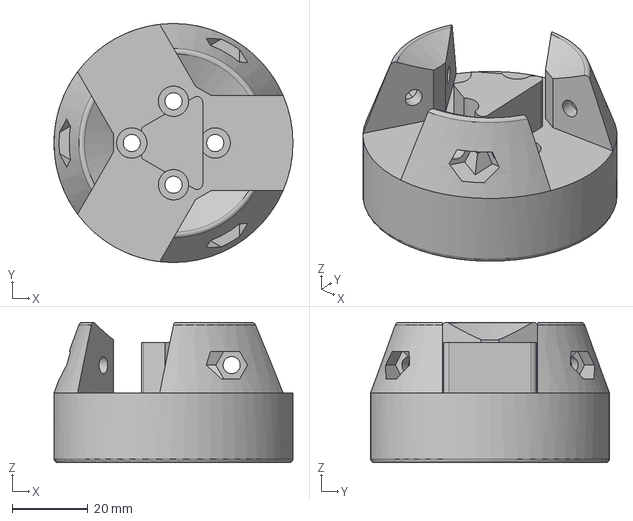
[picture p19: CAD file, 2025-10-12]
ORDER PRINTS/A6.1.4_HUB_6384.step
63.0 x 63.0 x 37.0 mm

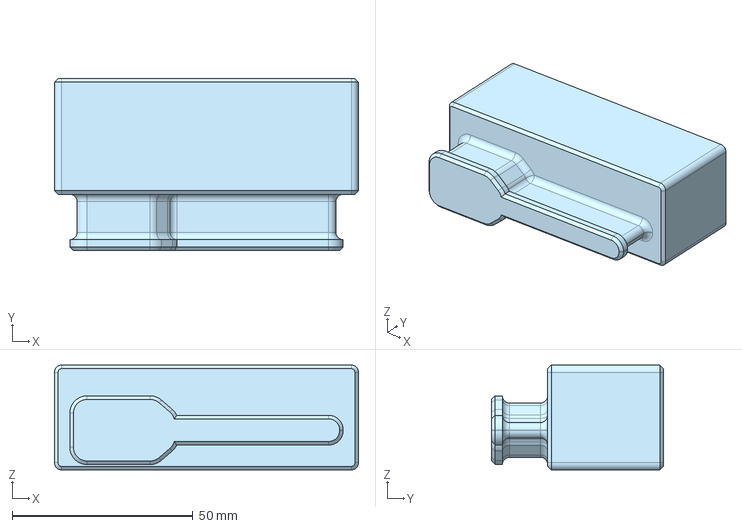
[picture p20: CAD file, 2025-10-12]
MAKE PARTS/B1_BATTERY_COVER.step
84.0 x 47.5 x 29.0 mm

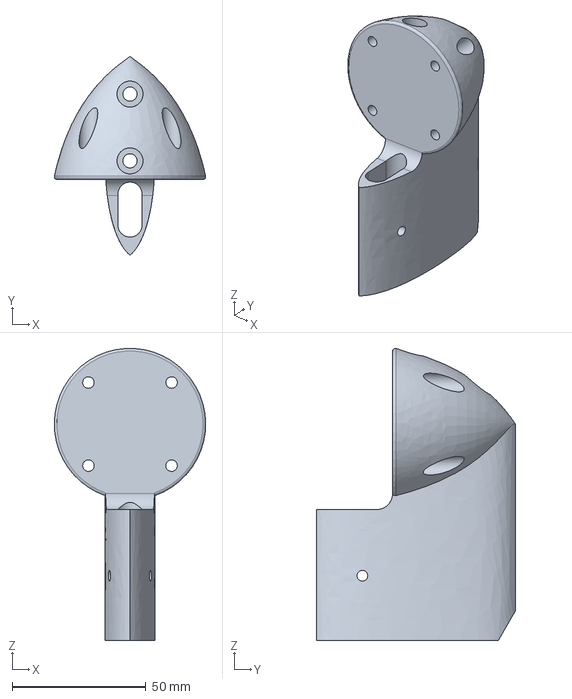
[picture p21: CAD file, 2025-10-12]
ORDER PRINTS/A6.2_POD_SIMPLIFIED.step
56.7 x 74.4 x 109.3 mm

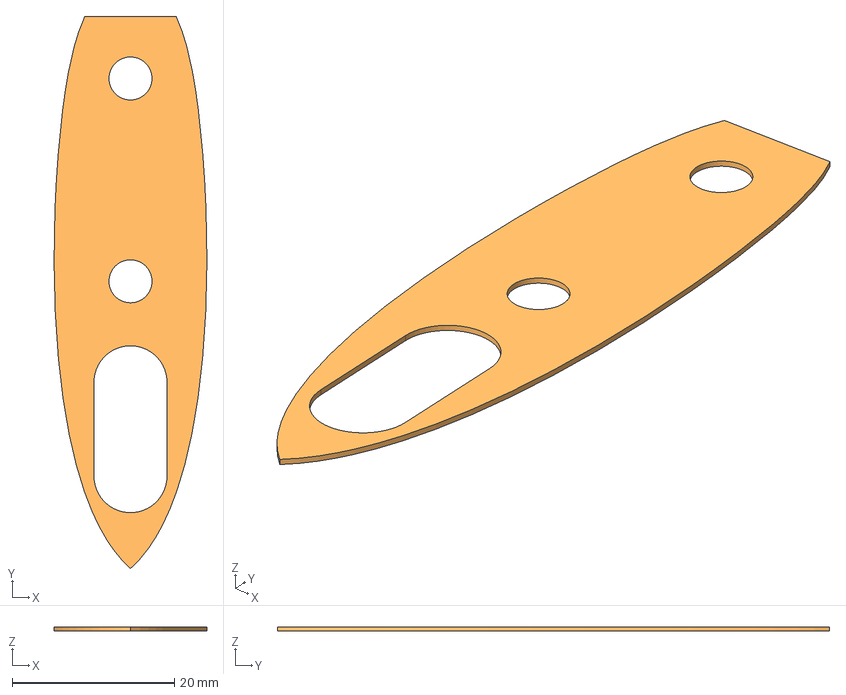
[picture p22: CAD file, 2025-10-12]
MAKE PARTS/A15_POD_SEAL.step
18.8 x 68.0 x 0.5 mm

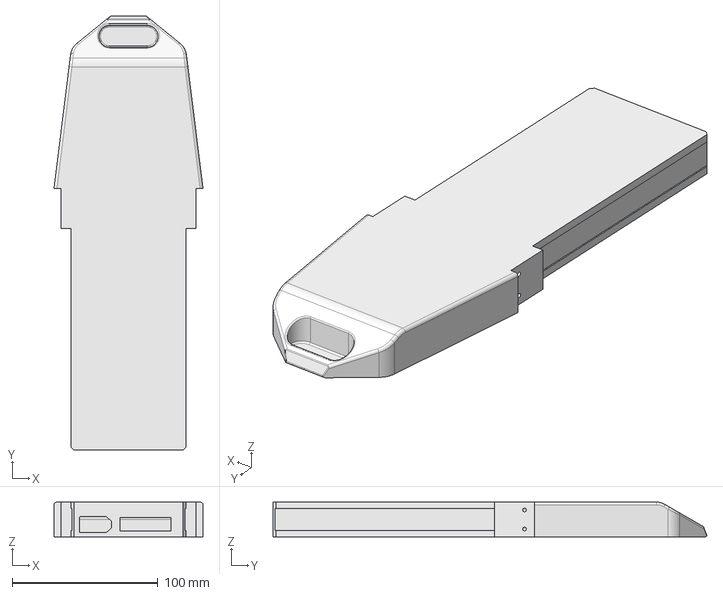
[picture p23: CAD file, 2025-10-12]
MAKE PARTS/A7.2_12S1P_BOX.step
102.2 x 297.5 x 24.0 mm

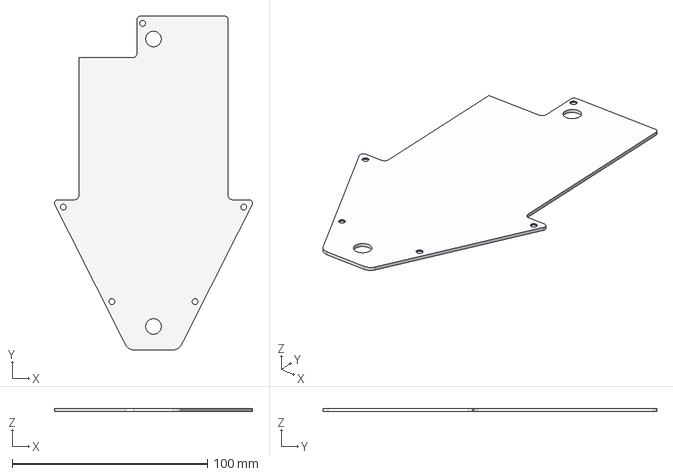
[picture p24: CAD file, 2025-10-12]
MAKE PARTS/A2_CTRL_COVER.step
101.4 x 171.0 x 1.50 mm

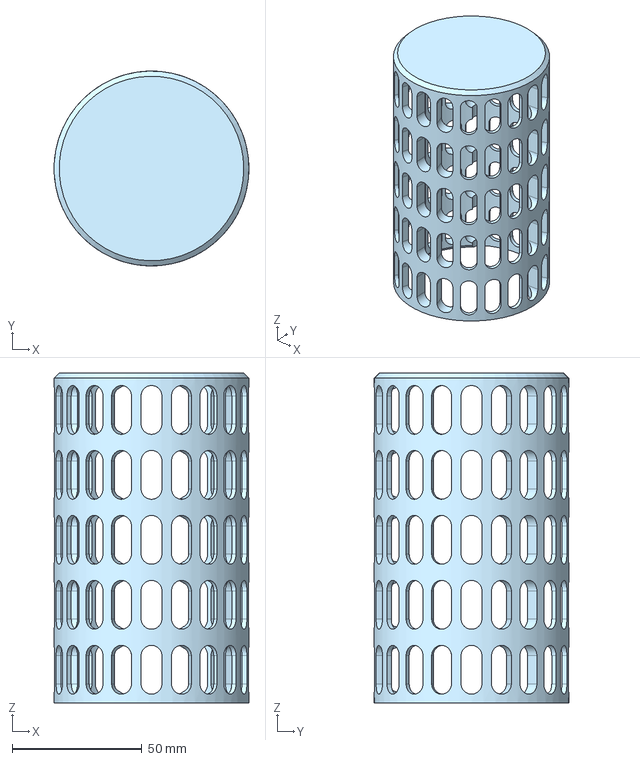
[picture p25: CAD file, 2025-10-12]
MAKE PARTS/B2_PROP_GUARD.step
75.0 x 75.0 x 127.0 mm

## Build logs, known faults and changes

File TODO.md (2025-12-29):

TODO :

+ rework the rib to spread the load
+ Ensure the MAYTECH rx model is correct (it did not fit 100% on my print, measure error?)
+ Record the potting volume at about 190 grams of material, work on the cover to reduce that
+ Programm and config (VESC EXPRESS, REMOTE)
+ Check Flycolor / sequire ESC integration possibility

DONE :

+ electronics schematic
+ add the correct screws FHC M8x55 and pod screws to the model for future reference
+ Programm and config (VESC)

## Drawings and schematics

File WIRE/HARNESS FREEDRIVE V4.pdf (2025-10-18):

## Bundle X1|X3

X1

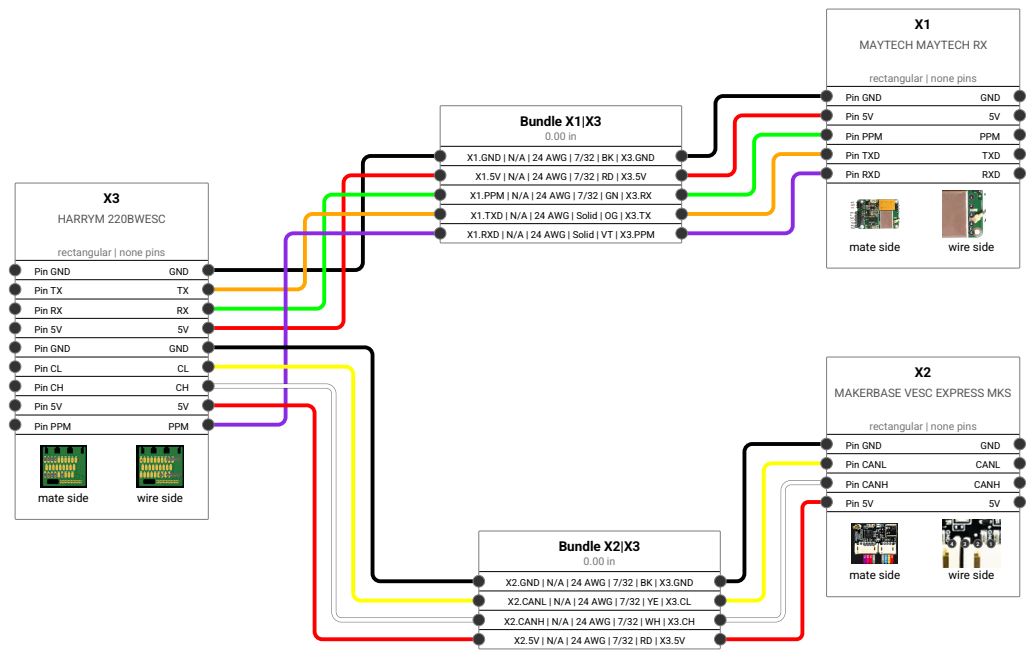
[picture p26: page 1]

X1.GND | N/A | 24 AWG | 7/32 | BK | X3.GND
X1.5V | N/A | 24 AWG | 7/32 | RD | X3.5V
X1.PPM | N/A | 24 AWG | 7/32 | GN | X3.RX
X1.TXD | N/A | 24 AWG | Solid | OG | X3.TX
X1.RXD | N/A | 24 AWG | Solid | VT | X3.PPM

MAKERBASE VESC EXPRESS MKS

X2.GND | N/A | 24 AWG | 7/32 | BK | X3.GND
X2.CANL | N/A | 24 AWG | 7/32 | YE | X3.CL
X2.CANH | N/A | 24 AWG | 7/32 | WH | X3.CH
X2.5V | N/A | 24 AWG | 7/32 | RD | X3.5V

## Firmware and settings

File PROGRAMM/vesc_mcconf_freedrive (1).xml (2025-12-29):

<?xml version="1.0" encoding="UTF-8"?>
<MCConfiguration>
    <ConfigVersion>3</ConfigVersion>
    <pwm_mode>1</pwm_mode>
    <comm_mode>0</comm_mode>
    <motor_type>2</motor_type>
    <sensor_mode>0</sensor_mode>
    <l_current_max>165</l_current_max>
    <l_current_min>-57.2</l_current_min>
    <l_in_current_max>50</l_in_current_max>
    <l_in_current_min>-20</l_in_current_min>
    <l_in_current_map_start>1</l_in_current_map_start>
    <l_in_current_map_filter>0.005</l_in_current_map_filter>
    <l_abs_current_max>250</l_abs_current_max>
    <l_min_erpm>-22000</l_min_erpm>
    <l_max_erpm>22000</l_max_erpm>
    <l_erpm_start>0.8</l_erpm_start>
    <l_max_erpm_fbrake>300</l_max_erpm_fbrake>
    <l_max_erpm_fbrake_cc>1500</l_max_erpm_fbrake_cc>
    <l_min_vin>15</l_min_vin>
    <l_max_vin>60</l_max_vin>
    <l_battery_cut_start>35</l_battery_cut_start>
    <l_battery_cut_end>32</l_battery_cut_end>
    <l_battery_regen_cut_start>1000</l_battery_regen_cut_start>
    <l_battery_regen_cut_end>1100</l_battery_regen_cut_end>
    <l_slow_abs_current>0</l_slow_abs_current>
    <l_temp_fet_start>85</l_temp_fet_start>
    <l_temp_fet_end>100</l_temp_fet_end>
    <l_temp_motor_start>85</l_temp_motor_start>
    <l_temp_motor_end>100</l_temp_motor_end>
    <l_temp_accel_dec>0.15</l_temp_accel_dec>
    <l_min_duty>0.005</l_min_duty>
    <l_max_duty>0.95</l_max_duty>
    <l_watt_max>1.5e+06</l_watt_max>
    <l_watt_min>-1.5e+06</l_watt_min>
    <l_current_max_scale>1</l_current_max_scale>
    <l_current_min_scale>1</l_current_min_scale>
    <l_duty_start>1</l_duty_start>
    <sl_min_erpm>150</sl_min_erpm>
    <sl_min_erpm_cycle_int_limit>1100</sl_min_erpm_cycle_int_limit>
    <sl_max_fullbreak_current_dir_change>10</sl_max_fullbreak_current_dir_change>
    <sl_cycle_int_limit>62</sl_cycle_int_limit>
    <sl_phase_advance_at_br>0.8</sl_phase_advance_at_br>
    <sl_cycle_int_rpm_br>80000</sl_cycle_int_rpm_br>
    <sl_bemf_coupling_k>600</sl_bemf_coupling_k>
    <hall_table__0>-1</hall_table__0>
    <hall_table__1>1</hall_table__1>
    <hall_table__2>3</hall_table__2>
    <hall_table__3>2</hall_table__3>
    <hall_table__4>5</hall_table__4>
    <hall_table__5>6</hall_table__5>
    <hall_table__6>4</hall_table__6>
    <hall_table__7>-1</hall_table__7>
    <hall_sl_erpm>2000</hall_sl_erpm>
    <foc_current_kp>0.0297</foc_current_kp>
    <foc_current_ki>24.45</foc_current_ki>
    <foc_f_zv>30000</foc_f_zv>
    <foc_dt_us>0.12</foc_dt_us>
    <foc_encoder_inverted>0</foc_encoder_inverted>
    <foc_encoder_offset>180</foc_encoder_offset>
    <foc_encoder_ratio>7</foc_encoder_ratio>
    <foc_sensor_mode>0</foc_sensor_mode>
    <foc_pll_kp>2000</foc_pll_kp>
    <foc_pll_ki>30000</foc_pll_ki>
    <foc_motor_l>2.975e-05</foc_motor_l>
    <foc_motor_ld_lq_diff>8.47e-06</foc_motor_ld_lq_diff>
    <foc_motor_r>0.0244</foc_motor_r>
    <foc_motor_flux_linkage>0.004969</foc_motor_flux_linkage>
    <foc_observer_gain>4.05e+07</foc_observer_gain>
    <foc_observer_gain_slow>0.05</foc_observer_gain_slow>
    <foc_observer_offset>-1</foc_observer_offset>
    <foc_duty_dowmramp_kp>50</foc_duty_dowmramp_kp>
    <foc_duty_dowmramp_ki>1000</foc_duty_dowmramp_ki>
    <foc_start_curr_dec>1</foc_start_curr_dec>
    <foc_start_curr_dec_rpm>2500</foc_start_curr_dec_rpm>
    <foc_openloop_rpm>700</foc_openloop_rpm>
    <foc_openloop_rpm_low>0</foc_openloop_rpm_low>
    <foc_d_gain_scale_start>0.9</foc_d_gain_scale_start>
    <foc_d_gain_scale_max_mod>0.2</foc_d_gain_scale_max_mod>
    <foc_sl_openloop_hyst>0.1</foc_sl_openloop_hyst>
    <foc_sl_openloop_time_lock>0</foc_sl_openloop_time_lock>
    <foc_sl_openloop_time_ramp>0.1</foc_sl_openloop_time_ramp>
    <foc_sl_openloop_time>0.05</foc_sl_openloop_time>
    <foc_sl_openloop_boost_q>0</foc_sl_openloop_boost_q>
    <foc_sl_openloop_max_q>-1</foc_sl_openloop_max_q>
    <foc_hall_table__0>255</foc_hall_table__0>
    <foc_hall_table__1>255</foc_hall_table__1>
    <foc_hall_table__2>255</foc_hall_table__2>
    <foc_hall_table__3>255</foc_hall_table__3>
    <foc_hall_table__4>255</foc_hall_table__4>
    <foc_hall_table__5>255</foc_hall_table__5>
    <foc_hall_table__6>255</foc_hall_table__6>
    <foc_hall_table__7>255</foc_hall_table__7>
    <foc_hall_interp_erpm>500</foc_hall_interp_erpm>
    <foc_sl_erpm_start>2500</foc_sl_erpm_start>
    <foc_sl_erpm>4000</foc_sl_erpm>
    <foc_control_sample_mode>0</foc_control_sample_mode>
    <foc_current_sample_mode>0</foc_current_sample_mode>
    <foc_sat_comp_mode>0</foc_sat_comp_mode>
    <foc_sat_comp>0</foc_sat_comp>
    <foc_temp_comp>0</foc_temp_comp>
    <foc_temp_comp_base_temp>25</foc_temp_comp_base_temp>
    <foc_current_filter_const>0.1</foc_current_filter_const>
    <foc_cc_decoupling>0</foc_cc_decoupling>
    <foc_observer_type>3</foc_observer_type>
    <foc_hfi_voltage_start>20</foc_hfi_voltage_start>
    <foc_hfi_voltage_run>4</foc_hfi_voltage_run>
    <foc_hfi_voltage_max>6</foc_hfi_voltage_max>
    <foc_hfi_gain>0.3</foc_hfi_gain>
    <foc_hfi_max_err>0.15</foc_hfi_max_err>
    <foc_hfi_hyst>0</foc_hfi_hyst>
    <foc_sl_erpm_hfi>3000</foc_sl_erpm_hfi>
    <foc_hfi_start_samples>5</foc_hfi_start_samples>
    <foc_hfi_obs_ovr_sec>0.001</foc_hfi_obs_ovr_sec>
    <foc_hfi_samples>1</foc_hfi_samples>
    <foc_offsets_cal_on_boot>1</foc_offsets_cal_on_boot>
    <foc_offsets_current__0>2028.07</foc_offsets_current__0>
    <foc_offsets_current__1>2028.31</foc_offsets_current__1>
    <foc_offsets_current__2>2026.59</foc_offsets_current__2>
    <foc_offsets_voltage__0>-0.0028</foc_offsets_voltage__0>
    <foc_offsets_voltage__1>0</foc_offsets_voltage__1>
    <foc_offsets_voltage__2>0.0027</foc_offsets_voltage__2>
    <foc_offsets_voltage_undriven__0>0</foc_offsets_voltage_undriven__0>
    <foc_offsets_voltage_undriven__1>0</foc_offsets_voltage_undriven__1>
    <foc_offsets_voltage_undriven__2>0</foc_offsets_voltage_undriven__2>
    <foc_phase_filter_enable>1</foc_phase_filter_enable>
    <foc_phase_filter_disable_fault>1</foc_phase_filter_disable_fault>
    <foc_phase_filter_max_erpm>4000</foc_phase_filter_max_erpm>
    <foc_mtpa_mode>0</foc_mtpa_mode>
    <foc_fw_current_max>0</foc_fw_current_max>
    <foc_fw_duty_start>0.9</foc_fw_duty_start>
    <foc_fw_q_current_factor>0.02</foc_fw_q_current_factor>
    <foc_fw_ramp_time>0.2</foc_fw_ramp_time>
    <foc_speed_soure>0</foc_speed_soure>
    <foc_short_ls_on_zero_duty>0</foc_short_ls_on_zero_duty>
    <sp_pid_loop_rate>5</sp_pid_loop_rate>
    <s_pid_kp>0.004</s_pid_kp>
    <s_pid_ki>0.004</s_pid_ki>
    <s_pid_kd>0.0001</s_pid_kd>
    <s_pid_kd_filter>0.2</s_pid_kd_filter>
    <s_pid_min_erpm>900</s_pid_min_erpm>
    <s_pid_allow_braking>1</s_pid_allow_braking>
    <s_pid_ramp_erpms_s>25000</s_pid_ramp_erpms_s>
    <s_pid_speed_source>0</s_pid_speed_source>
    <p_pid_kp>0.025</p_pid_kp>
    <p_pid_ki>0</p_pid_ki>
    <p_pid_kd>0</p_pid_kd>
    <p_pid_offset>0</p_pid_offset>
    <p_pid_kd_proc>0.00035</p_pid_kd_proc>
    <p_pid_kd_filter>0.2</p_pid_kd_filter>
    <p_pid_ang_div>1</p_pid_ang_div>
    <p_pid_gain_dec_angle>0</p_pid_gain_dec_angle>
    <cc_startup_boost_duty>0.01</cc_startup_boost_duty>
    <cc_min_current>0.05</cc_min_current>
    <cc_gain>0.0046</cc_gain>
    <cc_ramp_step_max>0.04</cc_ramp_step_max>
    <m_fault_stop_time_ms>500</m_fault_stop_time_ms>
    <m_duty_ramp_step>0.02</m_duty_ramp_step>
    <m_current_backoff_gain>0.5</m_current_backoff_gain>
    <m_encoder_counts>8192</m_encoder_counts>
    <m_encoder_sin_amp>1</m_encoder_sin_amp>
    <m_encoder_cos_amp>1</m_encoder_cos_amp>
    <m_encoder_sin_offset>1.65</m_encoder_sin_offset>
    <m_encoder_cos_offset>1.65</m_encoder_cos_offset>
    <m_encoder_sincos_filter_constant>0.5</m_encoder_sincos_filter_constant>
    <m_encoder_sincos_phase_correction>0</m_encoder_sincos_phase_correction>
    <m_sensor_port_mode>0</m_sensor_port_mode>
    <m_invert_direction>0</m_invert_direction>
    <m_drv8301_oc_mode>0</m_drv8301_oc_mode>
    <m_drv8301_oc_adj>16</m_drv8301_oc_adj>
    <m_bldc_f_sw_min>3000</m_bldc_f_sw_min>
    <m_bldc_f_sw_max>35000</m_bldc_f_sw_max>
    <m_dc_f_sw>25000</m_dc_f_sw>
    <m_ntc_motor_beta>3380</m_ntc_motor_beta>
    <m_out_aux_mode>0</m_out_aux_mode>
    <m_motor_temp_sens_type>0</m_motor_temp_sens_type>
    <m_ptc_motor_coeff>0.61</m_ptc_motor_coeff>
    <m_ntcx_ptcx_res>10000</m_ntcx_ptcx_res>
    <m_ntcx_ptcx_temp_base>25</m_ntcx_ptcx_temp_base>
    <m_hall_extra_samples>3</m_hall_extra_samples>
    <m_batt_filter_const>45</m_batt_filter_const>
    <si_motor_poles>14</si_motor_poles>
    <si_gear_ratio>1</si_gear_ratio>
    <si_wheel_diameter>0.083</si_wheel_diameter>
    <si_battery_type>0</si_battery_type>
    <si_battery_cells>12</si_battery_cells>
    <si_battery_ah>4.5</si_battery_ah>
    <si_motor_nl_current>1</si_motor_nl_current>
    <motor_brand>Unnamed</motor_brand>
    <motor_model>Not Specified</motor_model>
    <motor_weight>0</motor_weight>
    <motor_sensor_type>0</motor_sensor_type>
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

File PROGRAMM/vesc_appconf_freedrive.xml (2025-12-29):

<?xml version="1.0" encoding="UTF-8"?>
<APPConfiguration>
    <ConfigVersion>3</ConfigVersion>
    <controller_id>37</controller_id>
    <timeout_msec>500</timeout_msec>
    <timeout_brake_current>0</timeout_brake_current>
    <can_status_rate_1>50</can_status_rate_1>
    <can_status_rate_2>5</can_status_rate_2>
    <can_status_msgs_r1>15</can_status_msgs_r1>
    <can_status_msgs_r2>0</can_status_msgs_r2>
    <can_baud_rate>2</can_baud_rate>
    <pairing_done>0</pairing_done>
    <permanent_uart_enabled>1</permanent_uart_enabled>
    <shutdown_mode>7</shutdown_mode>
    <can_mode>0</can_mode>
    <uavcan_esc_index>0</uavcan_esc_index>
    <uavcan_raw_mode>0</uavcan_raw_mode>
    <uavcan_raw_rpm_max>50000</uavcan_raw_rpm_max>
    <uavcan_status_current_mode>0</uavcan_status_current_mode>
    <servo_out_enable>0</servo_out_enable>
    <kill_sw_mode>0</kill_sw_mode>
    <app_to_use>4</app_to_use>
    <app_ppm_conf.ctrl_type>2</app_ppm_conf.ctrl_type>
    <app_ppm_conf.pid_max_erpm>15000</app_ppm_conf.pid_max_erpm>
    <app_ppm_conf.hyst>0.15</app_ppm_conf.hyst>
    <app_ppm_conf.pulse_start>1</app_ppm_conf.pulse_start>
    <app_ppm_conf.pulse_end>2.001</app_ppm_conf.pulse_end>
    <app_ppm_conf.pulse_center>1.5005</app_ppm_conf.pulse_center>
    <app_ppm_conf.median_filter>1</app_ppm_conf.median_filter>
    <app_ppm_conf.safe_start>1</app_ppm_conf.safe_start>
    <app_ppm_conf.throttle_exp>0</app_ppm_conf.throttle_exp>
    <app_ppm_conf.throttle_exp_brake>0</app_ppm_conf.throttle_exp_brake>
    <app_ppm_conf.throttle_exp_mode>2</app_ppm_conf.throttle_exp_mode>
    <app_ppm_conf.ramp_time_pos>0.4</app_ppm_conf.ramp_time_pos>
    <app_ppm_conf.ramp_time_neg>0.2</app_ppm_conf.ramp_time_neg>
    <app_ppm_conf.multi_esc>1</app_ppm_conf.multi_esc>
    <app_ppm_conf.tc>0</app_ppm_conf.tc>
    <app_ppm_conf.tc_max_diff>3000</app_ppm_conf.tc_max_diff>
    <app_ppm_conf.max_erpm_for_dir>4000</app_ppm_conf.max_erpm_for_dir>
    <app_ppm_conf.smart_rev_max_duty>0.07</app_ppm_conf.smart_rev_max_duty>
    <app_ppm_conf.smart_rev_ramp_time>3</app_ppm_conf.smart_rev_ramp_time>
    <app_adc_conf.ctrl_type>0</app_adc_conf.ctrl_type>
    <app_adc_conf.hyst>0.15</app_adc_conf.hyst>
    <app_adc_conf.voltage_start>0.9</app_adc_conf.voltage_start>
    <app_adc_conf.voltage_end>3</app_adc_conf.voltage_end>
    <app_adc_conf.voltage_min>0</app_adc_conf.voltage_min>
    <app_adc_conf.voltage_max>3.5</app_adc_conf.voltage_max>
    <app_adc_conf.voltage_center>2</app_adc_conf.voltage_center>
    <app_adc_conf.voltage2_start>0.9</app_adc_conf.voltage2_start>
    <app_adc_conf.voltage2_end>3</app_adc_conf.voltage2_end>
    <app_adc_conf.use_filter>1</app_adc_conf.use_filter>
    <app_adc_conf.safe_start>1</app_adc_conf.safe_start>
    <app_adc_conf.buttons>0</app_adc_conf.buttons>
    <app_adc_conf.voltage_inverted>0</app_adc_conf.voltage_inverted>
    <app_adc_conf.voltage2_inverted>0</app_adc_conf.voltage2_inverted>
    <app_adc_conf.throttle_exp>0</app_adc_conf.throttle_exp>
    <app_adc_conf.throttle_exp_brake>0</app_adc_conf.throttle_exp_brake>
    <app_adc_conf.throttle_exp_mode>2</app_adc_conf.throttle_exp_mode>
    <app_adc_conf.ramp_time_pos>0.3</app_adc_conf.ramp_time_pos>
    <app_adc_conf.ramp_time_neg>0.1</app_adc_conf.ramp_time_neg>
    <app_adc_conf.multi_esc>1</app_adc_conf.multi_esc>
    <app_adc_conf.tc>0</app_adc_conf.tc>
    <app_adc_conf.tc_max_diff>3000</app_adc_conf.tc_max_diff>
    <app_adc_conf.update_rate_hz>500</app_adc_conf.update_rate_hz>
    <app_uart_baudrate>115200</app_uart_baudrate>
    <app_chuk_conf.ctrl_type>0</app_chuk_conf.ctrl_type>
    <app_chuk_conf.hyst>0.15</app_chuk_conf.hyst>
    <app_chuk_conf.ramp_time_pos>0.4</app_chuk_conf.ramp_time_pos>
    <app_chuk_conf.ramp_time_neg>0.2</app_chuk_conf.ramp_time_neg>
    <app_chuk_conf.stick_erpm_per_s_in_cc>3000</app_chuk_conf.stick_erpm_per_s_in_cc>
    <app_chuk_conf.throttle_exp>0</app_chuk_conf.throttle_exp>
    <app_chuk_conf.throttle_exp_brake>0</app_chuk_conf.throttle_exp_brake>
    <app_chuk_conf.throttle_exp_mode>2</app_chuk_conf.throttle_exp_mode>
    <app_chuk_conf.multi_esc>1</app_chuk_conf.multi_esc>
    <app_chuk_conf.tc>0</app_chuk_conf.tc>
    <app_chuk_conf.tc_max_diff>3000</app_chuk_conf.tc_max_diff>
    <app_chuk_conf.use_smart_rev>1</app_chuk_conf.use_smart_rev>
    <app_chuk_conf.smart_rev_max_duty>0.07</app_chuk_conf.smart_rev_max_duty>
    <app_chuk_conf.smart_rev_ramp_time>3</app_chuk_conf.smart_rev_ramp_time>
    <app_nrf_conf.speed>1</app_nrf_conf.speed>
    <app_nrf_conf.power>3</app_nrf_conf.power>
    <app_nrf_conf.crc_type>1</app_nrf_conf.crc_type>
    <app_nrf_conf.retry_delay>0</app_nrf_conf.retry_delay>
    <app_nrf_conf.retries>3</app_nrf_conf.retries>
    <app_nrf_conf.channel>76</app_nrf_conf.channel>
    <app_nrf_conf.address__0>198</app_nrf_conf.address__0>
    <app_nrf_conf.address__1>199</app_nrf_conf.address__1>
    <app_nrf_conf.address__2>0</app_nrf_conf.address__2>
    <app_nrf_conf.send_crc_ack>1</app_nrf_conf.send_crc_ack>
    <app_pas_conf.ctrl_type>0</app_pas_conf.ctrl_type>
    <app_pas_conf.sensor_type>0</app_pas_conf.sensor_type>
    <app_pas_conf.pedal_rpm_start>10</app_pas_conf.pedal_rpm_start>
    <app_pas_conf.pedal_rpm_end>180</app_pas_conf.pedal_rpm_end>
    <app_pas_conf.invert_pedal_direction>0</app_pas_conf.invert_pedal_direction>
    <app_pas_conf.magnets>24</app_pas_conf.magnets>
    <app_pas_conf.use_filter>1</app_pas_conf.use_filter>
    <app_pas_conf.current_scaling>0.1</app_pas_conf.current_scaling>
    <app_pas_conf.ramp_time_pos>0.6</app_pas_conf.ramp_time_pos>
    <app_pas_conf.ramp_time_neg>0.3</app_pas_conf.ramp_time_neg>
    <app_pas_conf.update_rate_hz>500</app_pas_conf.update_rate_hz>
    <imu_conf.type>1</imu_conf.type>
    <imu_conf.mode>0</imu_conf.mode>
    <imu_conf.filter>1</imu_conf.filter>
    <imu_conf.accel_lowpass_filter_x>0</imu_conf.accel_lowpass_filter_x>
    <imu_conf.accel_lowpass_filter_y>0</imu_conf.accel_lowpass_filter_y>
    <imu_conf.accel_lowpass_filter_z>0</imu_conf.accel_lowpass_filter_z>
    <imu_conf.gyro_lowpass_filter>0</imu_conf.gyro_lowpass_filter>
    <imu_conf.sample_rate_hz>200</imu_conf.sample_rate_hz>
    <imu_conf.use_magnetometer>1</imu_conf.use_magnetometer>
    <imu_conf.accel_confidence_decay>1</imu_conf.accel_confidence_decay>
    <imu_conf.mahony_kp>0.3</imu_conf.mahony_kp>
    <imu_conf.mahony_ki>0</imu_conf.mahony_ki>
    <imu_conf.madgwick_beta>0.1</imu_conf.madgwick_beta>
    <imu_conf.rot_roll>0</imu_conf.rot_roll>
    <imu_conf.rot_pitch>0</imu_conf.rot_pitch>
    <imu_conf.rot_yaw>0</imu_conf.rot_yaw>
    <imu_conf.accel_offsets__0>0</imu_conf.accel_offsets__0>
    <imu_conf.accel_offsets__1>0</imu_conf.accel_offsets__1>
    <imu_conf.accel_offsets__2>0</imu_conf.accel_offsets__2>
    <imu_conf.gyro_offsets__0>0</imu_conf.gyro_offsets__0>
    <imu_conf.gyro_offsets__1>0</imu_conf.gyro_offsets__1>
    <imu_conf.gyro_offsets__2>0</imu_conf.gyro_offsets__2>
</APPConfiguration>

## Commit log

2025-10-12 initial data load
    [BOM of V4 system.xlsx]
2025-10-12 INITIAL CAD LOADOUT
    [A10_BATT_SEAL.step, A15_POD_SEAL.step, A16_TPU_PAD.step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]
2025-10-12 Update BOM of V4 system.xlsx
    [BOM of V4 system.xlsx]
2025-10-18 Add wiring schematics to WIRE.MD
2025-11-04 Update readme to reflect current testing conditions
    Removed outdated project status and community validation details.
2025-11-20 Controller V4.11
    Updated controller base to fit 39mm wide flipsky pro 6.7 mini
    [A1_CTRL_V4.step]
2025-11-20 update cad
    change M5 screw lenght to 80mm and modify POD
    Update the controller part to 4.11
2025-12-29 Upload config files for VESC
    CONFIG FILES FOR 6384-120KV, 12S1P P45B, VESC EXPRESS + MAYTECH RX, HArryM 220 VESC
    [vesc_appconf_freedrive.xml, vesc_mcconf_freedrive (1).xml]
2026-06-12 docs: update README with June 2026 5085 motor tests and community replication builds
2026-10-06 docs: add Season 4 turbine (jet drive) development log with 5085 tests, water test screenshots, build photos
    - docs/turbine-development.md: full S4 jet dev log (why turbine, timeline,
    test unit specs, 5085 motor path, first water test results 13 Sept 2026,
    dedicated system concept v1, S4 board build Oct 2026, open gaps)
    - readme.md: new News section (turbine first test + 5085/ti + dedicated build)
    - NEWS.md: entries from 2026-05-12 through 2026-10-05
    - research.md: cross-link to the turbine log
    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
2026-10-06 docs: trim news item in readme; drop custom board build and power cartridge sections from turbine log
    The dedicated S4 board build and in-board cartridge concept are separate
    developments, not part of the freedrive system.
2026-10-27 research: add Oct 2026 jet intel, scaling law, and CAD/ride media
    - research.md: new section 7 field intel (hub cracking materials, potting vs
    thermal pads, 868 MHz RF, remote mod, power limits, session range),
    new section 8 impeller scaling law T ~ (P*D)^(2/3) with 40->50 mm table,
    status block for the 5065 320 KV + 8 mm shaft purchase, option D path.
    - docs/turbine-development.md: timeline to 27 Oct, design v2 (17 Sep concept),
    design v3 (50 mm two-stage turbine), hardware purchase, thread design debate.
    - NEWS.md: Aug-Oct 2026 thread digest. TODO.md: jet build actions.
    - docs/media/s4-jet-2026-10: CAD, part and ride photos from the thread.
2026-10-27 research: verify the Flite AMP 25 kg thrust figure online
    Sources: fliteboard.com US/EU + products/ampjet, wetfeetsports, The Inertia
    review, Foiling Magazine test, foilfun comparison table, foilsurfing.net.
    - 25 kg confirmed by three parties, but it is a PEAK figure: 2 x AMPCells,
    10 s boost cycle. One cell gives less. Not a continuous rating.
    - Flite publishes no power, voltage, current or impeller diameter. Our
    1.5-2 kW row is an estimate and is now labelled as such.
    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
2026-10-27 research: bracket the AMPJet impeller size (60-75 mm) and fix the duty cycle
